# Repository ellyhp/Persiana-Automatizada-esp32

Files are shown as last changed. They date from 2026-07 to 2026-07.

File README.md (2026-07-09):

# 🪟 AutoShade — Persiana Automatizada con ESP32 + Blynk

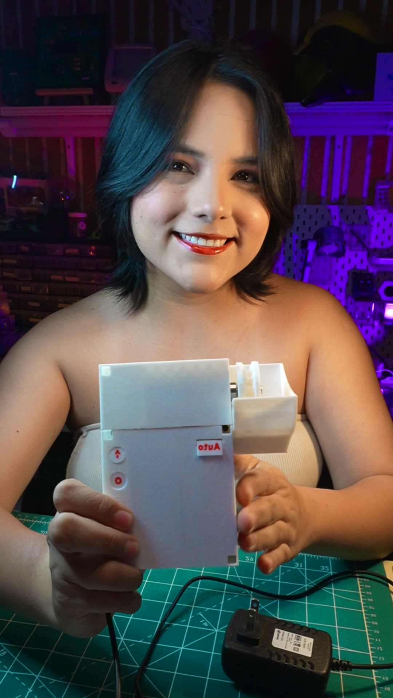
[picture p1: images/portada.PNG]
Persiana Automatizada


> Control inteligente de persiana motorizada vía botones físicos y app móvil, con protección de límite mecánico y memoria persistente.






---

## 📹 Video del proyecto

> 🎬 https://www.tiktok.com/@ellygmr/video/7660350983762955541
---

## 🖨️ Archivos STL para impresion 3D

> 🔗 **[Descargar archivos STL en MakerWorld](https://makerworld.com/es/models/3011631-esp32-smart-blind-controller-wifi-blynk)** *DESCARGAR*

---

## ✨ ¿Que hace este sistema?

- **Control manual** — el motor sube o baja mientras se mantiene presionado el boton, fisico o desde la app.
- **Control automatico** — un toque en Auto ejecuta el ciclo completo de apertura o cierre.
- **Modo Programacion** — define cuanto dura el recorrido completo que usa Auto.
- **Modo Limite** — define el tope maximo de apertura para proteger el mecanismo y el motor.
- **Logs en tiempo real** — todo lo que sucede se refleja en el Terminal de la app Blynk.
- **Memoria persistente** — el tiempo y el limite configurados sobreviven reinicios.

---

## ⚡ Descripcion del circuito

El ESP32 DevKit es el cerebro del sistema. Lee los botones, gestiona la logica y se comunica con la app via WiFi.

El motor DC de **35 RPM a 12V** es controlado por el driver **TB6612FNG**, que actua como intermediario entre el ESP32 (3.3V) y el motor (12V). Recibe tres senales: AIN1 y AIN2 para la direccion de giro, y PWMA para la velocidad via PWM.

La alimentacion viene de una sola fuente de **12V**. El **convertidor LM2596** toma esos 12V y los reduce a 5V estables para el ESP32, eliminando la necesidad de una segunda fuente.

Fuente 12V
|
|---> VM del TB6612FNG ---> Motor DC 35RPM 12V
|
'---> LM2596 (step-down) ---> 5V ---> ESP32 DevKit
|
GPIO 25 ---> AIN1
GPIO 26 ---> AIN2
GPIO 27 ---> PWMA
GPIO 32 ---> Boton Subir
GPIO 33 ---> Boton Bajar
GPIO 12 ---> Boton Stop
GPIO 13 ---> Boton Auto
GPIO  4 ---> Buzzer

---

## 🛒 Lista de componentes y presupuesto (AliExpress 2026)

| Componente | Especificacion | USD | MXN |
|---|---|---|---|
| ESP32 DevKit V1 | WiFi + Bluetooth, dual core | $4.50 - $7.50 | $88 - $146 |
| Driver TB6612FNG | H-bridge 1.2A, hasta 15V | $0.80 - $1.50 | $16 - $29 |
| Convertidor DC-DC LM2596 | Step-down ajustable 1.5V-35V | $0.50 - $1.20 | $10 - $23 |
| Motor DC 12V 35RPM | Con reductora | $3.00 - $12.00 | $58 - $234 |
| Fuente de alimentacion 12V | Minimo 1-2A | $3.50 - $8.00 | $68 - $156 |
| 4 pulsadores | Tact switch momentaneo | $0.50 - $1.00 | $10 - $20 |
| Buzzer activo | 3-5V señal continua | $0.30 - $0.80 | $6 - $16 |
| Cables y protoboard | Conexiones y soporte | $1.50 - $3.00 | $29 - $58 |
| **TOTAL** | | **$14.60 - $35** | **$285 - $682** |

> Precios con envio estandar gratuito desde AliExpress. Tipo de cambio: ~$19.50 MXN/USD.

---

## 📱 Pines virtuales Blynk

| Pin | Widget | Modo | Funcion |
|---|---|---|---|
| V0 | Button | Switch | Abrir (subir) |
| V1 | Button | Switch | Cerrar (bajar) |
| V2 | Button | Push | Stop / configuracion |
| V3 | Button | Push | Auto ciclo completo |
| V4 | Terminal | - | Log en tiempo real |

---

## 🎮 Modos especiales (boton Stop)

| Accion | Resultado |
|---|---|
| 1 toque | Detiene el motor |
| 2 toques rapidos (menos de 1 seg) | Entra a modo Limite |
| 3 toques rapidos (menos de 1 seg) | Entra a modo Programacion |
| Mantener 3 segundos (fisico) | Entra a modo Programacion |
| 1 toque dentro de un modo | Guarda y sale |

---

105 ## 📁 Estructura del repositorio

```text
Persiana-Automatizada-esp32/
|
|-- Codigo/
|   '-- persiana_esp32.ino
|
|-- Diagrama/
|   '-- Persiana_bb.png
|
|-- images/
|   |-- portada.jpg
|   '-- instalacion_01.jpg
|
|-- README.md
|-- manual_persiana.pdf
'-- manual_blynk_persiana.pdf
```
123
124  ---

## 🔧 Instalacion rapida

1. Instala **Arduino IDE** con soporte para ESP32 core 3.x
2. Instala la libreria **Blynk** desde el Gestor de Librerias
3. Crea un Template en [blynk.cloud](https://blynk.cloud) con los pines V0 a V4
4. Edita las primeras lineas del codigo:

```cpp
#define BLYNK_TEMPLATE_ID   "TMPLxxxxxx"
#define BLYNK_TEMPLATE_NAME "Persiana"
#define BLYNK_AUTH_TOKEN    "xxxxxxxxxxxx"
char ssid[] = "TU_RED_WIFI";
char pass[] = "TU_CONTRASEÑA";
```

5. Carga al ESP32 y sigue el `manual_blynk_persiana.pdf`

---

## 📚 Documentacion incluida

| Archivo | Contenido |
|---|---|
| manual_persiana.pdf | Uso completo: botones, Programacion y Limite |
| manual_blynk_persiana.pdf | Configuracion de Blynk Cloud y la app movil |

---

## 🤝 Creditos

Proyecto por **@ellygmr**. Gracias a la comunidad maker y a **Bambu Lab**.

Si lo construyes, ¡etiquetame en mis redes!






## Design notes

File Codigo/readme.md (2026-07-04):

# Persiana Automatizada — ESP32 + Blynk

Control de persiana motorizada vía botones físicos y app Blynk IoT, con protección de límite mecánico y memoria persistente.

---

## ¿Qué hace?

- **Control manual**: el motor sube o baja mientras se mantiene presionado el botón (físico o app).
- **Control automático**: un toque en Auto ejecuta el ciclo completo de apertura o cierre.
- **Modo Programación**: define cuánto dura el recorrido completo que usa Auto.
- **Modo Límite**: define el tope máximo de apertura para proteger el mecanismo.
- **Logs en tiempo real**: todo lo que normalmente va al Monitor Serie también aparece en el Terminal de la app.

---

## Hardware

| Componente | Pin ESP32 |
|---|---|
| TB6612 AIN1 | GPIO 25 |
| TB6612 AIN2 | GPIO 26 |
| TB6612 PWMA | GPIO 27 |
| Botón Subir | GPIO 32 |
| Botón Bajar | GPIO 33 |
| Botón Stop | GPIO 12 |
| Botón Auto | GPIO 13 |
| Buzzer | GPIO 4 |

---

## Dependencias

- [Blynk](https://github.com/blynkkk/blynk-library) — control remoto vía app
- `Preferences.h` — incluida en el core de ESP32, guarda la configuración en flash

> Requiere **ESP32 Arduino core 3.x**. Si usas una versión anterior, reemplaza `ledcAttach()` por `ledcSetup()` + `ledcAttachPin()`.

---

## Configuración rápida

1. Crea un Template en [blynk.cloud](https://blynk.cloud) con 5 pines virtuales (V0–V4).
2. Reemplaza en el código:
```cpp
   #define BLYNK_TEMPLATE_ID   "TMPLxxxxxx"
   #define BLYNK_TEMPLATE_NAME "Persiana"
   #define BLYNK_AUTH_TOKEN    "xxxxxxxxxxxx"
   char ssid[] = "TU_RED_WIFI";
   char pass[] = "TU_CONTRASEÑA";
```
3. Compila y carga al ESP32.

---

## Pines virtuales Blynk

| Pin | Función | Modo widget |
|---|---|---|
| V0 | Abrir (Subir) | Switch |
| V1 | Cerrar (Bajar) | Switch |
| V2 | Stop / entrar modos | Push |
| V3 | Auto | Push |
| V4 | Terminal de logs | Terminal |

---

## Modos especiales (botón Stop)

| Toques en Stop | Resultado |
|---|---|
| 1 toque | Detiene el motor |
| 2 toques rápidos | Entra a modo **Límite** |
| 3 toques rápidos | Entra a modo **Programación** |
| 1 toque (dentro de un modo) | Guarda y sale |

> En físico también se puede entrar a Programación manteniendo Stop presionado 3 segundos.

---

## Estructura del código
setup()
└── Inicializa pines, PWM, WiFi y Blynk
loop()
├── Blynk.run()              → mantiene la conexión activa
├── detectarTapStopFisico()  → detecta flancos en el botón físico
├── resolverTapStopPendiente()→ decide modo según cantidad de taps
├── procesarModoLimite()     → ajuste del tope máximo
├── procesarModoProgramacion()→ ajuste del tiempo de recorrido
├── ejecutarAuto()           → ciclo completo abrir/cerrar
└── procesarManual()         → control momentáneo subir/bajar
Funciones de motor:
├── openMotor()   → AIN1=HIGH, AIN2=LOW,  PWM=MOTOR_SPEED
├── closeMotor()  → AIN1=LOW,  AIN2=HIGH, PWM=MOTOR_SPEED
└── stopMotor()   → AIN1=LOW,  AIN2=LOW,  PWM=0

---

## Notas

- La posición se calcula por tiempo transcurrido (no hay sensor físico). Si el ESP32 se reinicia con la persiana en una posición distinta de cerrada, recalibra bajándola del todo manualmente.
- Los valores de `tiempoMax` y `limiteMax` se guardan en flash y persisten entre reinicios.
- Durante el ciclo Auto, `Blynk.run()` se llama dentro del bucle para mantener la conexión activa.

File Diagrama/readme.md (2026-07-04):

Aquí puedes acceder al diagrama de las respectivas conexiones del sistema. :)

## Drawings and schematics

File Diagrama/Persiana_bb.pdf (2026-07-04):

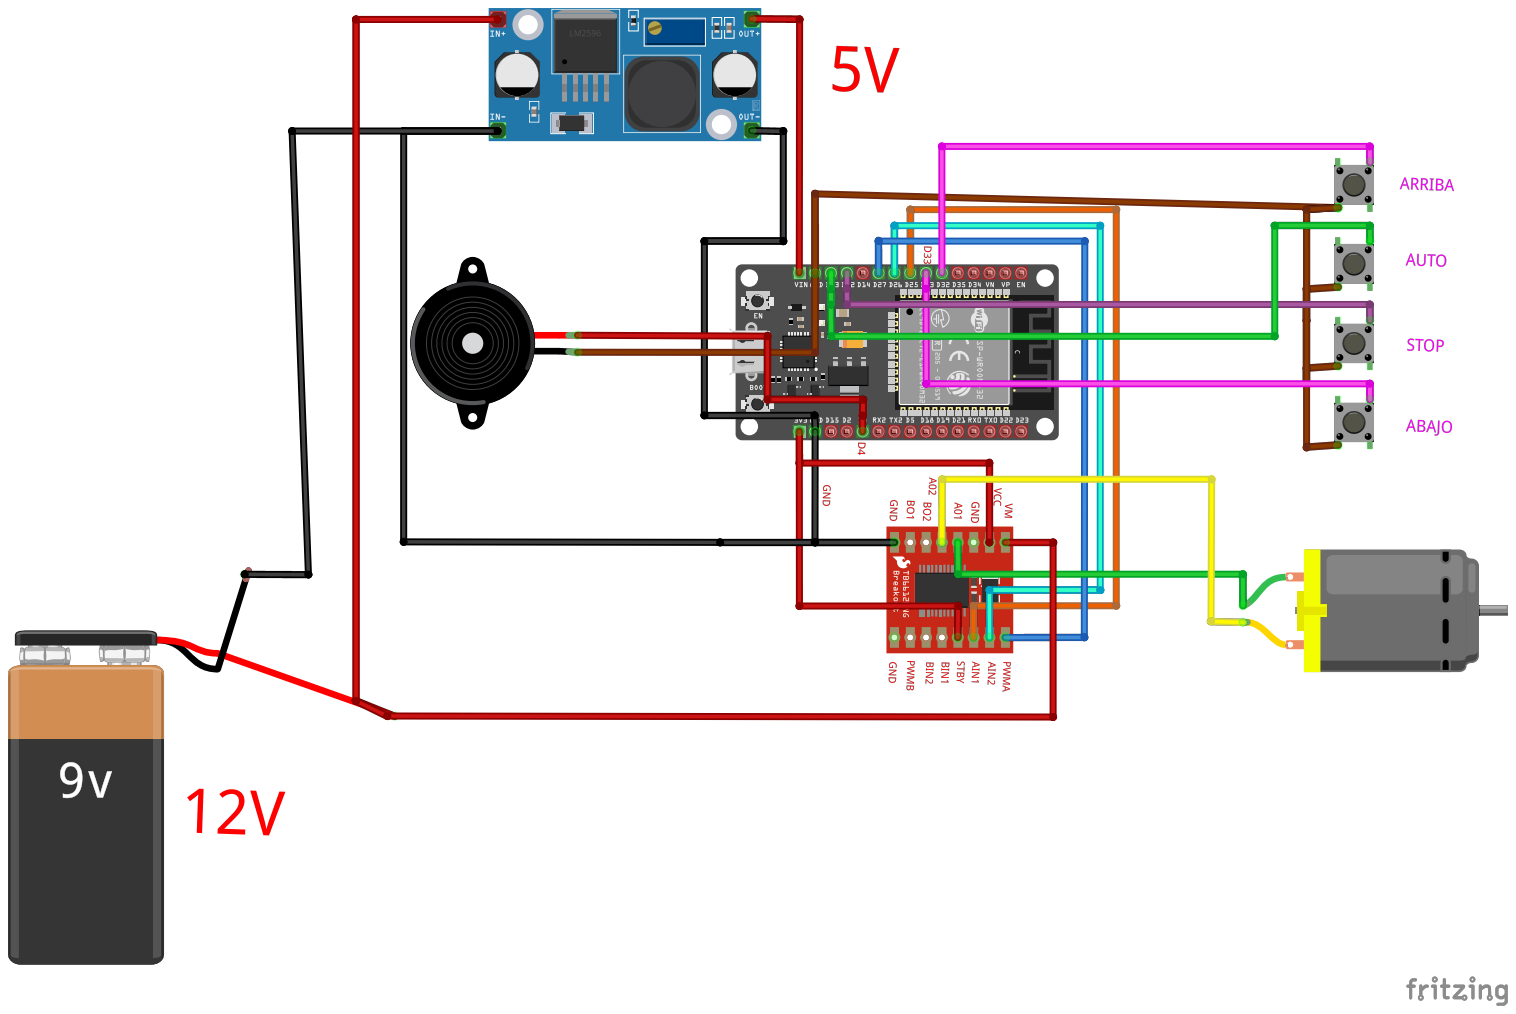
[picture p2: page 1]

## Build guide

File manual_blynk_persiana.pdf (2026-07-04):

# BLYNK

# Persiana Automatizada

## Manual de configuración y uso desde la app

Guía paso a paso para configurar la plataforma Blynk Cloud, crear los widgets en la app móvil y operar la persiana desde tu celular.

Compatible con Blynk IoT (nueva versión) · ESP32 con core 3.x

## 1. Requisitos previos

Antes de comenzar asegúrate de tener el código ya cargado y funcionando en el ESP32. Todos los pasos de esta guía se hacen desde el navegador (blynk.cloud) y desde la app móvil Blynk IoT.

Qué necesitas | Detalle
App móvil | Blynk IoT (App Store / Google Play) — no la versión legacy
Cuenta Blynk | Gratuita en blynk.cloud
ESP32 conectado | Con el código de la persiana ya cargado y con WiFi configurado

## 2. Configurar Blynk Cloud (desde el navegador)

Esta parte se hace una sola vez desde blynk.cloud. Entra con tu cuenta y sigue estos pasos:

### 2.1 Crear el Template

1 En el menú lateral, haz clic en Templates → + New Template.

2 Ponle el nombre Persiana, selecciona hardware ESP32 y conexión WiFi. Haz clic en Done.

3 Anota el BLYNK_TEMPLATE_ID y el BLYNK_TEMPLATE_NAME que aparecen en la pantalla; estos valores van al inicio del código.

### 2.2 Crear los Datastreams (pines virtuales)

4 Dentro del Template, ve a la pestaña Datastreams → + New Datastream → Virtual Pin. Crea los 5 siguientes:

Abrir (botón Subir) | V0

Data Type: Integer
Min / Max: 0 / 1
Uso en app: Botón modo Switch — mantener = mover motor
Cerrar (botón Bajar) | V1

Data Type: Integer
Min / Max: 0 / 1
Uso en app: Botón modo Switch — mantener = mover motor
Stop / Configuración | V2

Data Type: Integer
Min / Max: 0 / 1
Uso en app: Botón modo Push — 1 toque = stop / 2 = Límite / 3 = Prog.
Auto | V3

Data Type: Integer

Min / Max: 0 / 1
Uso en app: Botón modo Push — 1 toque = ciclo completo abrir/cerrar
Terminal / Log | V4

Data Type: String
Uso en app: Widget Terminal — muestra los mensajes del sistema en tiempo real

### 2.3 Crear el dispositivo y obtener el Auth Token

5 Ve a Devices → + New Device → From Template. Selecciona el template Persiana y haz clic en Create.

6 En la pantalla del dispositivo verás el Auth Token. Cópialo; lo necesitas en el código (BLYNK_AUTH_TOKEN).

7 Con los tres valores (Template ID, Template Name y Auth Token), actualiza las primeras líneas del código, compila y carga al ESP32.

¿Cómo saber si el ESP32 se conectó correctamente? En la pantalla del dispositivo en blynk.cloud, el indicador de estado debe cambiar a Online (verde) pocos segundos después de encender el ESP32.

## 3. Configurar la app móvil Blynk IoT

Abre la app, inicia sesión con tu cuenta y selecciona el dispositivo Persiana. Luego entra al modo edición del dashboard tocando el ícono de lápiz (✏) en la esquina superior derecha.

### 3.1 Botón ABRIR → V0

Arrastra un widget Button al dashboard. En sus propiedades:

### 1 Título: Abrir

### 2 Datastream: V0

### 3 Mode: Switch ← obligatorio

Por qué Switch y no Push: en modo Switch el botón envía 1 al presionar y 0 al soltar, igual que un pulsador físico. El motor se mueve solo mientras tu dedo está sobre el botón.

### 3.2 Botón CERRAR → V1

Mismo proceso que Abrir:

### 1 Título: Cerrar

### 2 Datastream: V1

### 3 Mode: Switch

BLYNK IOT
Persiana

⬆

ABRIR
V0 · Switch
⬇

CERRAR
V1 · Switch

⏹

STOP
V2 · Push
⚡

AUTO
V3 · Push

TERMINAL / LOG · V4

LOG
> Sistema iniciado
> Tiempo: 8.0 s

3 Mode: Switch | > Sin limite config.
| > ABRIENDO > DETENIDO

### 3.3 Botón STOP → V2

### 1 Título: Stop

### 2 Datastream: V2

### 3 Mode: Push

Este botón hace cosas distintas según cuántas veces lo toques: un toque = detiene el motor. Dos toques rápidos (menos de 1 segundo entre cada uno) = entra al modo Límite. Tres toques rápidos = entra al modo Programación. Dentro de cualquiera de esos modos, un solo toque = guarda y sale.

### 3.4 Botón AUTO → V3

### 1 Título: Auto

### 2 Datastream: V3

### 3 Mode: Push

Un solo toque ejecuta el ciclo completo: si la persiana está cerrada, la abre; si está abierta, la cierra. El sistema alterna en cada toque.

### 3.5 Widget Terminal → V4

1 Arrastra el widget Terminal al dashboard.

### 2 Datastream: V4

3 Activa la opción Auto scroll para que siempre se vea el mensaje más reciente.

Para qué sirve: muestra en tiempo real todo lo que pasa en el sistema (abriendo, cerrando, límite alcanzado, configuración guardada, etc.), igual que el Monitor Serie del Arduino IDE pero desde el celular.

## 4. Configurar el Límite máximo desde la app

El límite define hasta dónde puede subir la persiana. Si no lo configuras primero, el motor puede forzar el mecanismo.

1 Toca el botón Stop dos veces seguidas rápido (menos de 1 segundo entre cada toque). El Terminal mostrará: >>> MODO LIMITE y sonarás un beep.

2 Usa Abrir y Cerrar para llevar la persiana hasta el punto máximo que quieres permitir. El Terminal mostrará la posición en segundos en tiempo real.

3 Cuando llegues al punto deseado, toca Stop una sola vez. El Terminal mostrará: LIMITE GUARDADO y sonarán dos beeps.

Nota: en este modo no hay tope superior, ya que estás definiendo precisamente cuál será ese tope. El único límite es no bajar de cero (posición cerrada del todo).

## 5. Configurar el modo Programación desde la app

La programación define cuánto tiempo dura el ciclo completo que usa el botón Auto.

1 Toca el botón Stop tres veces seguidas rápido (menos de 1 segundo entre cada toque). El Terminal mostrará: >>> MODO PROGRAMACION y sonarás un beep.

2 Usa Abrir y Cerrar para ajustar la posición de apertura total deseada. Puedes corregirte libremente: si te pasas, baja un poco; el sistema cuenta la posición neta. No podrás superar el Límite guardado.

3 Cuando la persiana esté en el punto exacto de apertura total, toca Stop una sola vez. El Terminal mostrará: CONFIGURACION GUARDADA y sonarán dos beeps.

Importante: después de tocar Stop 2 o 3 veces, hay un instante (menos de 1 segundo) antes de que el modo se active. El sistema espera para confirmar cuántos toques diste. Es normal, no indica un error.

## 6. Uso diario desde la app

Botón en la app | Qué hace
Abrir (mantener) | El motor sube mientras el dedo está sobre el botón. Al soltar, se detiene. No supera el límite.
Cerrar (mantener) | El motor baja mientras el dedo está sobre el botón. Al soltar, se detiene.
Stop (1 toque) | Detiene el motor inmediatamente.
Auto (1 toque) | Abre o cierra el ciclo completo automáticamente según el tiempo programado.
Stop (2 toques) | Entra al modo Límite para redefinir el tope máximo.
Stop (3 toques) | Entra al modo Programación para redefinir el tiempo del ciclo Auto.

## 7. Resumen de configuración de widgets

⬆ ABRIR — V0

Widget: Button
Mode: Switch
Datastream: V0

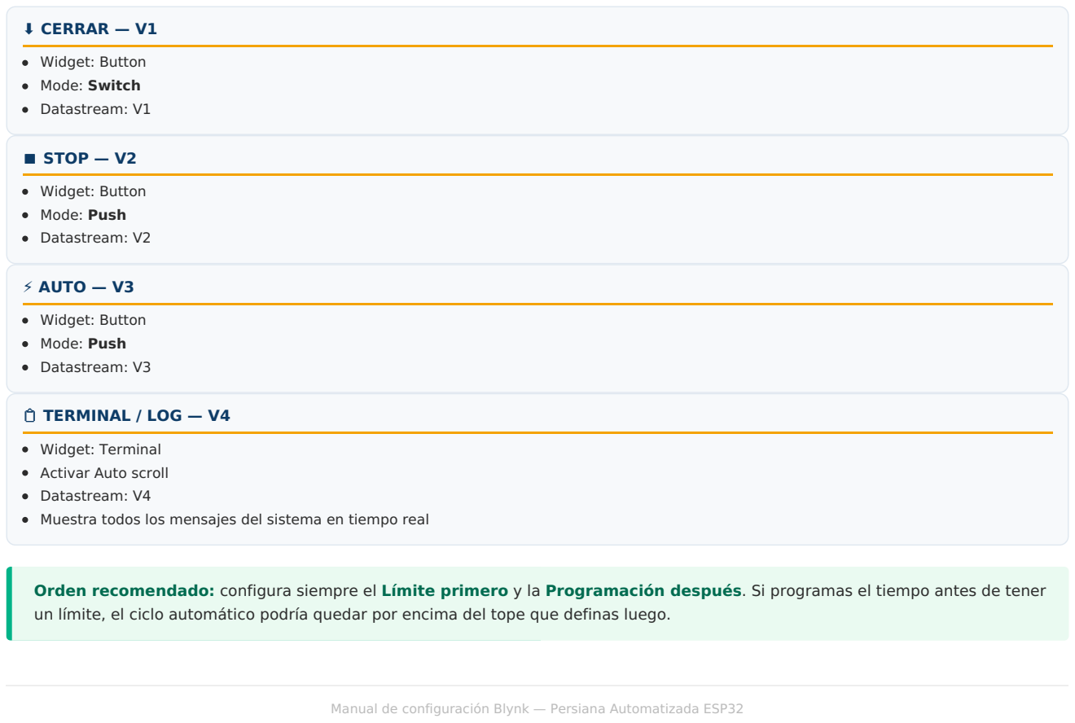
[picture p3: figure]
⬇ CERRAR — V1; Widget: Button Mode: Switch Datastream: V1; ⏹ STOP — V2; Widget: Button Mode: Push Datastream: V2; ⚡ AUTO — V3; Widget: Button Mode: Push Datastream: V3; TERMINAL / LOG — V4; Widget: Terminal Activar Auto scroll Datastream: V4

Muestra todos los mensajes del sistema en tiempo real

Orden recomendado: configura siempre el Límite primero y la Programación después. Si programas el tiempo antes de tener un límite, el ciclo automático podría quedar por encima del tope que definas luego.

Manual de configuración Blynk — Persiana Automatizada ESP32

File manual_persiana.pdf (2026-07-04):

# PERSIANA AUTOMATIZADA

### Manual de Usuario Programación, Límites y Botones

Sistema de control vía botones físicos y app Blynk

## 01 Botones del sistema

El dispositivo cuenta con cuatro botones físicos. Los mismos controles están disponibles en la app Blynk desde el celular.

Botón | Función principal
Subir | Abre la persiana mientras se mantiene presionado
Bajar | Cierra la persiana mientras se mantiene presionado
Stop | Detiene el motor; también da acceso a los modos de configuración
Auto | Ejecuta un ciclo completo de apertura o cierre con un solo toque

Control manual

Mantén presionado Subir para abrir, o Bajar para cerrar. El motor se mueve solo mientras el botón está presionado y se detiene al soltarlo, tanto desde el dispositivo como desde la app.

Protección automática: si la persiana llega al límite máximo configurado, el botón Subir deja de tener efecto aunque se
mantenga presionado. Esto evita que se enrede o se fuerce el motor.

Control automático

Presiona Auto una sola vez. Si la persiana está cerrada, se abrirá por completo; si está abierta, se cerrará por completo. Alterna cada vez que se presiona.

## 02 Configurar el Límite máximo

Define hasta dónde puede subir la persiana, como medida de seguridad para evitar que se enrede o se dañe el motor.

1 Entrar al modo: presiona Stop dos veces seguidas, en menos de 1 segundo entre cada toque (físico o app). Un sonido

2 Ajustar: usa Subir y Bajar normalmente hasta llevar la persiana al punto donde se debe fijar el tope máximo.

3 Guardar: presiona Stop una sola vez. Dos sonidos confirman que el límite quedó guardado y se salió del modo.

Para cambiar el límite más adelante, repite este mismo proceso. No es necesario borrar nada antes: el nuevo valor reemplaza automáticamente al guardado.

## 03 Configurar el modo Programación

Define cuánto dura el recorrido completo que utiliza el botón Auto.

1 Entrar al modo: mantén presionado Stop durante 3 segundos (solo físico), o presiónalo tres veces seguidas en menos de 1 segundo entre cada toque (físico o app). Un sonido confirma la entrada.

2 Ajustar: usa Subir y Bajar para llevar la persiana hasta la posición que debe alcanzar en un ciclo completo. Si te pasas, corrige bajando un poco y vuelve a subir: el sistema calcula automáticamente la posición final correcta. No es posible pasar del Límite ya configurado.

3 Guardar: presiona Stop una sola vez. Dos sonidos confirman que el tiempo quedó guardado.

## 04 Orden recomendado de configuración

Configura siempre el Límite primero, y la Programación después. Si se programa el recorrido antes de fijar un límite, este podría quedar recortado al definir el límite, obligando a reprogramar.

1 Verifica que la persiana esté completamente cerrada (posición de referencia inicial).

2 Configura el Límite máximo (doble toque en Stop).

3 Configura el tiempo de Programación (triple toque o mantener Stop 3 segundos).

4 Prueba con Auto para confirmar que el ciclo completo funciona correctamente.

## 05 Resumen rápido

Acción en Stop | Resultado
1 toque | Detiene el motor
2 toques rápidos (< 1 seg entre cada uno) | Entra a modo Límite
3 toques rápidos, o mantener 3 segundos | Entra a modo Programación
1 toque (estando dentro de Límite o Programación) | Guarda y sale del modo

Nota sobre el tiempo de respuesta: después de tocar Stop dos o tres veces, hay un breve instante (menos de 1 segundo) antes de que el modo se active, mientras el sistema confirma cuántos toques se dieron. Es normal, no indica una falla.

Recalibración: si la persiana deja de detenerse en el punto exacto después de mucho uso, basta con bajarla del todo manualmente. El sistema vuelve a tomar esa posición como punto de referencia (cero) automáticamente.

Manual de Usuario — Sistema de Persiana Automatizada con control Blynk

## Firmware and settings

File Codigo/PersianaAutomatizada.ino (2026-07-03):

#define BLYNK_TEMPLATE_ID   "TMPLxxxxxx"
#define BLYNK_TEMPLATE_NAME "Persiana"
#define BLYNK_AUTH_TOKEN    "xxxxxxxxxxxx"

#include <WiFi.h>
#include <BlynkSimpleEsp32.h>
#include <Preferences.h>

Preferences prefs;

// ========== TB6612 ==========
#define AIN1 25
#define AIN2 26
#define PWMA 27

// ========== BOTONES ==========
#define BTN_UP     32
#define BTN_DOWN   13
#define BTN_STOP   12
#define BTN_AUTO   33

// ========== BUZZER ===========
#define BUZZER 4

// ========== PWM ==============
#define PWM_FREQ 1000
#define PWM_RES  8
#define MOTOR_SPEED 180

// ========== WIFI =============
char ssid[] = "TU_RED_WIFI";
char pass[] = "TU_CONTRASEÑA";

// ========== ESTADO GENERAL ===========
bool modoProgramacion = false;
bool modoLimite        = false;
bool persianaAbierta   = false;

unsigned long tiempoMax = 8000;
long          limiteMax = -1;

unsigned long inicioTiempo = 0;
int           signoTiempo  = 1;

long posicionActual = 0;

String ultimoEstado = "";

bool blynkUp   = false;
bool blynkDown = false;
bool blynkAuto = false;

// ========== Tap counter para el botón STOP ==========
#define TAP_INTERVALO 1000
int contadorTapStop = 0;
unsigned long ultimoTapStop = 0;
bool decisionTomada = false;

// ============================================================
void logBoth(String texto) {
  Serial.println(texto);
  Blynk.virtualWrite(V4, texto + "\n");
}

// ============================================================
BLYNK_WRITE(V0) { blynkUp = (param.asInt() == 1); }
BLYNK_WRITE(V1) { blynkDown = (param.asInt() == 1); }

BLYNK_WRITE(V2) {
  if (param.asInt() == 1) {
    logBoth(">>> [BLYNK] STOP");
    if (modoProgramacion) { guardarYSalirProgramacion(); return; }
    if (modoLimite)        { guardarYSalirLimite(); return; }
    registrarTapStop();
  }
}

BLYNK_WRITE(V3) {
  if (param.asInt() == 1) blynkAuto = true;
}

// ============================================================
void setup() {
  Serial.begin(115200);

  prefs.begin("persiana", false);
  tiempoMax = prefs.getULong("tiempo", 8000);
  limiteMax = prefs.getLong("limite", -1);

  pinMode(AIN1, OUTPUT);
  pinMode(AIN2, OUTPUT);
  pinMode(BTN_UP,   INPUT_PULLUP);
  pinMode(BTN_DOWN, INPUT_PULLUP);
  pinMode(BTN_STOP, INPUT_PULLUP);
  pinMode(BTN_AUTO, INPUT_PULLUP);
  pinMode(BUZZER, OUTPUT);

  // ===== CORRECCIÓN CORE 3.x =====
  ledcAttach(PWMA, PWM_FREQ, PWM_RES);

  stopMotor();

  Blynk.begin(BLYNK_AUTH_TOKEN, ssid, pass);
  Blynk.virtualWrite(V4, "clr");

  logBoth("");
  logBoth("=======================");
  logBoth("Sistema iniciado");
  logBoth("=======================");
  logBoth("Tiempo guardado: " + String(tiempoMax / 1000.0) + " s");

  if (limiteMax >= 0) logBoth("Limite guardado: " + String(limiteMax / 1000.0) + " s");
  else logBoth("Sin limite configurado");

  posicionActual = 0;
}

// ============================================================
void loop() {
  Blynk.run();

  detectarTapStopFisico();
  resolverTapStopPendiente();

  if (modoLimite)        { procesarModoLimite();       return; }
  if (modoProgramacion)  { procesarModoProgramacion(); return; }

  bool autoFisico = (digitalRead(BTN_AUTO) == LOW);
  bool autoBlynkEdge = blynkAuto;
  blynkAuto = false;

  static bool autoFisicoAnterior = false;
  bool autoFisicoEdge = (!autoFisicoAnterior && autoFisico);
  autoFisicoAnterior = autoFisico;

  if (autoFisicoEdge || autoBlynkEdge) {
    ejecutarAuto();
  }

  procesarManual();

  delay(100);
}

// ============================================================
bool puedeSubir() {
  if (limiteMax < 0) return true;
  return posicionActual < limiteMax;
}

bool puedeBajar() {
  return posicionActual > 0;
}

// ============================================================
void procesarManual() {

  bool subiendo = (digitalRead(BTN_UP) == LOW) || blynkUp;
  bool bajando  = (digitalRead(BTN_DOWN) == LOW) || blynkDown;

  if (subiendo && puedeSubir()) {
    if (ultimoEstado != "ABRIENDO") { logBoth(""); logBoth(">>> ABRIENDO"); ultimoEstado = "ABRIENDO"; }
    if (inicioTiempo == 0) { inicioTiempo = millis(); signoTiempo = 1; }
    openMotor();
    actualizarPosicionEnVivo();
  }
  else if (bajando && puedeBajar()) {
    if (ultimoEstado != "CERRANDO") { logBoth(""); logBoth(">>> CERRANDO"); ultimoEstado = "CERRANDO"; }
    if (inicioTiempo == 0) { inicioTiempo = millis(); signoTiempo = -1; }
    closeMotor();
    actualizarPosicionEnVivo();
  }
  else if (digitalRead(BTN_STOP) == LOW) {
    stopMotor();
    consolidarPosicion();
    if (ultimoEstado != "STOP") { logBoth(""); logBoth(">>> DETENIDO"); ultimoEstado = "STOP"; }
  }
  else {
    stopMotor();
    consolidarPosicion();
    if ((subiendo && !puedeSubir()) || (bajando && !puedeBajar())) {
      if (ultimoEstado != "LIMITE_TOPE") {
        logBoth(">>> LIMITE ALCANZADO, no se puede mover mas en esa direccion");
        ultimoEstado = "LIMITE_TOPE";
      }
    } else {
      ultimoEstado = "";
    }
  }
}

// ============================================================
void ejecutarAuto() {

  logBoth("");
  logBoth(">>> AUTO");

  if (!persianaAbierta) {
    logBoth("Abriendo");
    unsigned long t0 = millis();
    while (millis() - t0 < tiempoMax) {
      if (!puedeSubir()) break;
      openMotor();
      posicionActual += 50;
      delay(50);
      Blynk.run();
    }
    stopMotor();
    persianaAbierta = true;
  } else {
    logBoth("Cerrando");
    unsigned long t0 = millis();
    while (millis() - t0 < tiempoMax) {
      if (!puedeBajar()) break;
      closeMotor();
      posicionActual -= 50;
      delay(50);
      Blynk.run();
    }
    stopMotor();
    persianaAbierta = false;
  }

  if (posicionActual < 0) posicionActual = 0;
  if (limiteMax >= 0 && posicionActual > limiteMax) posicionActual = limiteMax;

  beep(1);
  delay(1000);
}

// ============================================================
void actualizarPosicionEnVivo() {
  if (inicioTiempo != 0) {
    long transcurrido = millis() - inicioTiempo;
    long delta = signoTiempo * transcurrido;
    long nuevaPos = posicionActual + delta;

    if (signoTiempo == 1 && limiteMax >= 0 && nuevaPos > limiteMax) {
      nuevaPos = limiteMax;
      stopMotor();
    }
    if (signoTiempo == -1 && nuevaPos < 0) {
      nuevaPos = 0;
      stopMotor();
    }

    posicionActual = nuevaPos;
    inicioTiempo = millis();
  }
}

void consolidarPosicion() {
  inicioTiempo = 0;
}

// ============================================================
// ---------- MODO PROGRAMACION ----------
void entrarModoProgramacion() {
  modoProgramacion = true;
  inicioTiempo = 0;
  logBoth("");
  logBoth(">>> MODO PROGRAMACION");
  logBoth("Posicion actual: " + String(posicionActual / 1000.0) + " s");
  beep(1);
}

void procesarModoProgramacion() {

  bool subiendo = ((digitalRead(BTN_UP) == LOW) || blynkUp) && puedeSubir();
  bool bajando  = ((digitalRead(BTN_DOWN) == LOW) || blynkDown) && puedeBajar();

  if (subiendo) {
    if (ultimoEstado != "ARRIBA") { logBoth(""); logBoth(">>> AJUSTANDO ARRIBA (+)"); ultimoEstado = "ARRIBA"; }
    if (inicioTiempo == 0) { inicioTiempo = millis(); signoTiempo = 1; }
    openMotor();
    actualizarPosicionEnVivo();
    mostrarPosicion();
  }
  else if (bajando) {
    if (ultimoEstado != "ABAJO") { logBoth(""); logBoth(">>> AJUSTANDO ABAJO (-)"); ultimoEstado = "ABAJO"; }
    if (inicioTiempo == 0) { inicioTiempo = millis(); signoTiempo = -1; }
    closeMotor();
    actualizarPosicionEnVivo();
    mostrarPosicion();
  }
  else {
    stopMotor();
    consolidarPosicion();
    ultimoEstado = "";
  }

  if (digitalRead(BTN_STOP) == LOW) {
    guardarYSalirProgramacion();
    delay(1000);
  }
}

void guardarYSalirProgramacion() {
  stopMotor();
  consolidarPosicion();

  tiempoMax = (unsigned long) posicionActual;
  prefs.putULong("tiempo", tiempoMax);

  logBoth("");
  logBoth("CONFIGURACION GUARDADA");
  logBoth("Tiempo: " + String(tiempoMax / 1000.0) + " s");

  beep(2);

  inicioTiempo = 0;
  modoProgramacion = false;
  ultimoEstado = "";
}

void mostrarPosicion() {
  static long ultimo = -999999;
  long segundos = posicionActual / 1000;
  if (segundos != ultimo) {
    ultimo = segundos;
    logBoth("Posicion: " + String(segundos) + " s");
  }
}

// ============================================================
// ---------- MODO LIMITE ----------
void entrarModoLimite() {
  modoLimite = true;
  inicioTiempo = 0;
  logBoth("");
  logBoth(">>> MODO LIMITE");
  logBoth("Posicion actual: " + String(posicionActual / 1000.0) + " s");
  beep(1);
}

void procesarModoLimite() {

  bool subiendo = (digitalRead(BTN_UP) == LOW) || blynkUp;
  bool bajando  = ((digitalRead(BTN_DOWN) == LOW) || blynkDown) && (posicionActual > 0);

  if (subiendo) {
    if (ultimoEstado != "ARRIBA_LIM") { logBoth(""); logBoth(">>> AJUSTANDO LIMITE ARRIBA (+)"); ultimoEstado = "ARRIBA_LIM"; }
    if (inicioTiempo == 0) { inicioTiempo = millis(); signoTiempo = 1; }
    openMotor();
    actualizarPosicionLibre();
    mostrarPosicion();
  }
  else if (bajando) {
    if (ultimoEstado != "ABAJO_LIM") { logBoth(""); logBoth(">>> AJUSTANDO LIMITE ABAJO (-)"); ultimoEstado = "ABAJO_LIM"; }
    if (inicioTiempo == 0) { inicioTiempo = millis(); signoTiempo = -1; }
    closeMotor();
    actualizarPosicionLibre();
    mostrarPosicion();
  }
  else {
    stopMotor();
    consolidarPosicion();
    ultimoEstado = "";
  }

  if (digitalRead(BTN_STOP) == LOW) {
    guardarYSalirLimite();
    delay(1000);
  }
}

void actualizarPosicionLibre() {
  if (inicioTiempo != 0) {
    long transcurrido = millis() - inicioTiempo;
    long nuevaPos = posicionActual + signoTiempo * transcurrido;
    if (nuevaPos < 0) { nuevaPos = 0; stopMotor(); }
    posicionActual = nuevaPos;
    inicioTiempo = millis();
  }
}

void guardarYSalirLimite() {
  stopMotor();
  consolidarPosicion();

  limiteMax = posicionActual;
  prefs.putLong("limite", limiteMax);

  logBoth("");
  logBoth("LIMITE GUARDADO");
  logBoth("Limite: " + String(limiteMax / 1000.0) + " s");

  beep(2);

  inicioTiempo = 0;
  modoLimite = false;
  ultimoEstado = "";
}

// ============================================================
// ---------- Detección de taps en STOP ----------
void detectarTapStopFisico() {
  static bool ultimoEstadoBtn = HIGH;
  bool actual = digitalRead(BTN_STOP);

  if (ultimoEstadoBtn == HIGH && actual == LOW && !modoProgramacion && !modoLimite) {
    registrarTapStop();
  }

  ultimoEstadoBtn = actual;
}

void registrarTapStop() {
  unsigned long ahora = millis();

  if (ahora - ultimoTapStop > TAP_INTERVALO) contadorTapStop = 1;
  else contadorTapStop++;

  ultimoTapStop = ahora;
  decisionTomada = false;
}

void resolverTapStopPendiente() {
  if (contadorTapStop == 0 || decisionTomada) return;
  if (modoProgramacion || modoLimite) { contadorTapStop = 0; return; }

  unsigned long ahora = millis();

  if (ahora - ultimoTapStop > TAP_INTERVALO) {
    if (contadorTapStop == 2)   entrarModoLimite();
    else if (contadorTapStop >= 3) entrarModoProgramacion();

    contadorTapStop = 0;
    decisionTomada = true;
  }
}

// ============================================================
// ===== CORRECCIÓN CORE 3.x: ledcWrite usa el pin, no el canal =====
void openMotor()  { digitalWrite(AIN1, HIGH); digitalWrite(AIN2, LOW);  ledcWrite(PWMA, MOTOR_SPEED); }
void closeMotor() { digitalWrite(AIN1, LOW);  digitalWrite(AIN2, HIGH); ledcWrite(PWMA, MOTOR_SPEED); }
void stopMotor()  { digitalWrite(AIN1, LOW);  digitalWrite(AIN2, LOW);  ledcWrite(PWMA, 0); }

void beep(int veces) {
  for (int i = 0; i < veces; i++) { digitalWrite(BUZZER, HIGH); delay(150); digitalWrite(BUZZER, LOW); delay(150); }
}
}

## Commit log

2026-07-04 agregue diagramas
    [Persiana.fzz]
2026-07-04 Agregue manual para el uso del sistema
